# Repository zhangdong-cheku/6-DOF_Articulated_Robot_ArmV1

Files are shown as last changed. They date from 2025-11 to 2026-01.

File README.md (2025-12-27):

# 6-DOF_Articulated_Robot_ArmV1
六自由度关节式机械臂6-DOF Articulated Robot ArmV1

机械臂本体五个自由度，末端执行器是一个自由度，如果有兴趣，可以在机械臂的基础上增加一个末端执行器。

<p align="center">
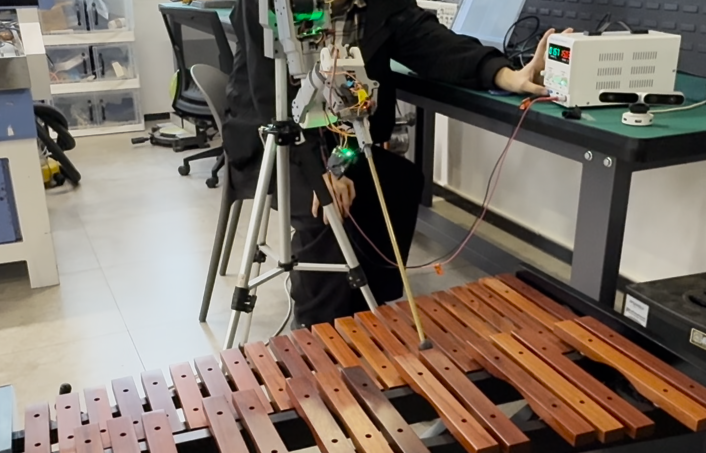
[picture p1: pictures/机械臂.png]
  
  
本项目是一款低成本、高扩展性的六自由度关节式机械臂，专为机器人爱好者、科研人员和学生设计。支持精准运动控制、路径规划、自定义任务编程，可广泛应用于教学演示、自动化实验、小型生产线作业等场景。
核心目标：降低机械臂开发门槛，提供从硬件设计到软件控制的完整开源方案，助力开发者快速搭建属于自己的机械臂系统。

This project is a low-cost, highly scalable six-degree-of-freedom articulated robotic arm, specially designed for robot enthusiasts, researchers and students. It supports precise motion control, path planning, and custom task programming, and can be widely applied in scenarios such as teaching demonstrations, automated experiments, and small-scale production line operations. 
Core objective: Lower the threshold for robotic arm development, provide a complete open-source solution from hardware design to software control, and assist developers in quickly building their own robotic arm systems.
<p align="center">
  

## 致谢
感谢项目组成员岳国文，田宇鑫在项目迭代与数据处理中做出的贡献，感谢张冬老师在项目方案上的精准指导，也感谢项目组其他成员的通力协作。

## 加入社区

<p align="center">
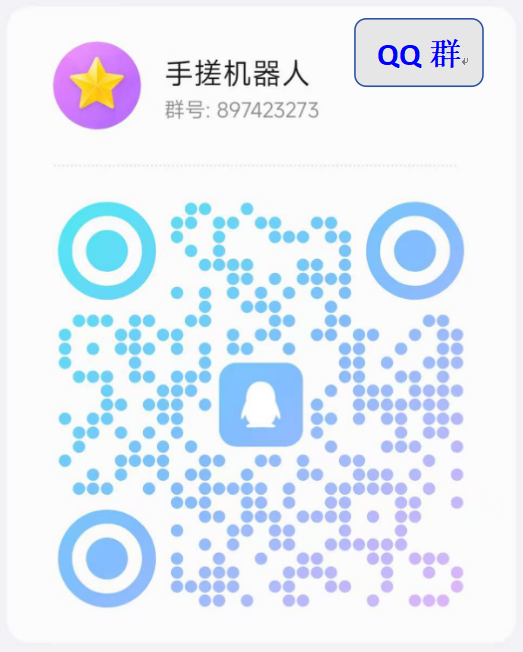
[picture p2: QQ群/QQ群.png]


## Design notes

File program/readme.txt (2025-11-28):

烧录前准备
在arduino_project中
1.修改int Motor_PP = 7;，将极对数修改为自己使用电机的极对数。
2.setPowerSupplyVoltage(15.6);  //!< 设置供电电压：15.6V，可设置为自己电源的供电电压，建议不超过15.6V

在Ble_Handler.cpp和Ble_Handler.h中
1.可通过修改uint8_t my_device_id = 6;  #define MY_DEVICE_ID 6  ,设置自己设备的ID号

在FOC.h中
1.#define GEAR_RATIO 225.0f，用来设置关节的减速比

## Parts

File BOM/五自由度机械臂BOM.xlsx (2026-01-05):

名称 | 规格 | 数量 | 价格（单价） | 淘宝链接 | 备注
控制板 | 2-F0C单板（含电流传感器） | 5 | 77 | https://item.taobao.com/item.htm?from=cart&id=888754845091&skuId=5734451161826&upStreamPrice=7700 | 控制板可以多买一个，防止板子烧坏，AS5600磁编码可以多准备几个。
无刷电机 | 5010-360KV标配 | 5 | 70 | https://item.taobao.com/item.htm?from=cart&id=707986229345&skuId=5146420343156&upStreamPrice=7000
磁编码器AS5600 |  | 5 | 6.05 | https://item.taobao.com/item.htm?id=944751197481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
耗材 | 银色10102【无料盘】 | 3 | 58.65 | https://detail.tmall.com/item.htm?from=cart&id=693972799714&skuId=4921295904036&upStreamPrice=5865 | 耗材的颜色决定你机械臂的颜色
红黑线纯铜二芯电线 | 无氧纯铜 红黑线2芯（10米）0.75平方毫米 | 1 | 12.65 | https://item.taobao.com/item.htm?ali_trackid=318_fea39e69447c78ab8311cdb6c2fe511b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
虎头润滑脂 | 0# | 1 | 60 | https://detail.tmall.com/item.htm?id=555743121657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 | 组装完成后，要涂润滑脂，降低摩擦。（也可以选择其它品牌粘稠度低的润滑脂）
电子端子线 | SH1.0/5P/10CM单头(5条) | 1 | 3.3 | https://item.taobao.com/item.htm?id=565360096163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 | 备用件，可以多准备一些
MR106ZZ普通级尺寸6*10*3 |  | 120 | 54 | https://item.taobao.com/item.htm?id=771766393836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
轴承6701ZZ |  | 20 | 23.8 | https://item.taobao.com/item.htm?from=cart&id=990391948357&skuId=6121385790174&upStreamPrice=119
轴承6809ZZ |  | 5 | 20 | https://detail.tmall.com/item.htm?from=cart&id=612627762952&skuId=4622777205969&upStreamPrice=400
圆柱头螺钉M3*50 |  | 20-30个 | 9.22（两包） | https://detail.tmall.com/item.htm?from=cart&id=684328822068&skuId=5937566553025&upStreamPrice=251
圆柱头螺钉M3*16 |  | 30 | 4.71（一包） | https://detail.tmall.com/item.htm?from=cart&id=684328822068&skuId=5937566337918&upStreamPrice=261
圆柱头螺钉M3*25 |  | 30 | 6.28（一包） | https://detail.tmall.com/item.htm?from=cart&id=684328822068&skuId=5937566337934&upStreamPrice=398
圆柱头螺钉M3*3 |  | 10 | 4.45（一包） | https://detail.tmall.com/item.htm?from=cart&id=684328822068&skuId=5937566337977&upStreamPrice=235
沉头螺钉M3*4 |  | 20 | 6（一包） | https://detail.tmall.com/item.htm?from=cart&id=693377485791&skuId=5968664858309&upStreamPrice=398
B型平键6*6*15 |  | 5 | 14 | https://detail.tmall.com/item.htm?from=cart&id=986192425745&skuId=5949249685444&upStreamPrice=180
六角铜柱4*14 |  | 5 | 29 | https://detail.tmall.com/item.htm?from=cart&id=542213588710&skuId=5026844310974&upStreamPrice=480
热熔螺母M3*4*5 |  | 120 | 18.48（7包） | https://detail.tmall.com/item.htm?from=cart&id=809364062256&skuId=5496541308886&upStreamPrice=144
螺母M3 |  | 20-30个 | 5.03（一包） | https://detail.tmall.com/item.htm?id=634913276373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
赛克电烙铁 | 852D+(标配) |  | 230 | https://item.taobao.com/item.htm?id=927081057466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 | 实验室型号，仅供参考
鼎策学生电源 | DC3020S30V20A锁定/预设编码调节 |  | 430 | https://item.taobao.com/item.htm?id=563785564816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
备注：如果发现错误，欢迎大家在技术交流群里提出，会及时更新。

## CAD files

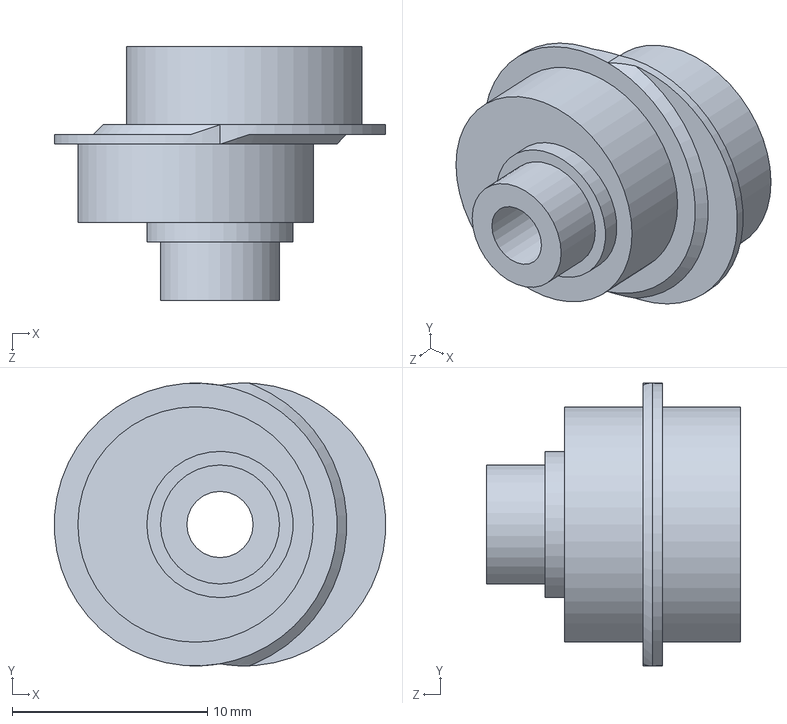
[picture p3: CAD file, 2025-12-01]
1.第一自由度/1.5.偏心轴。.SLDPRT
17.0 x 14.5 x 13.0 mm

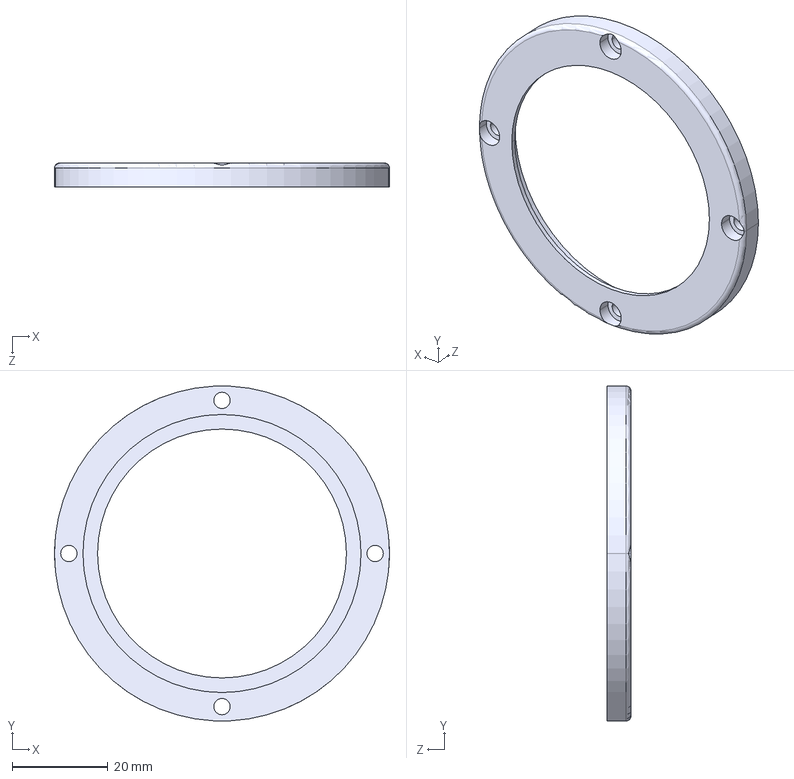
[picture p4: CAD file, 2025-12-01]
2.第二自由度/2.2二级外圈.STEP
70.0 x 70.0 x 5.00 mm

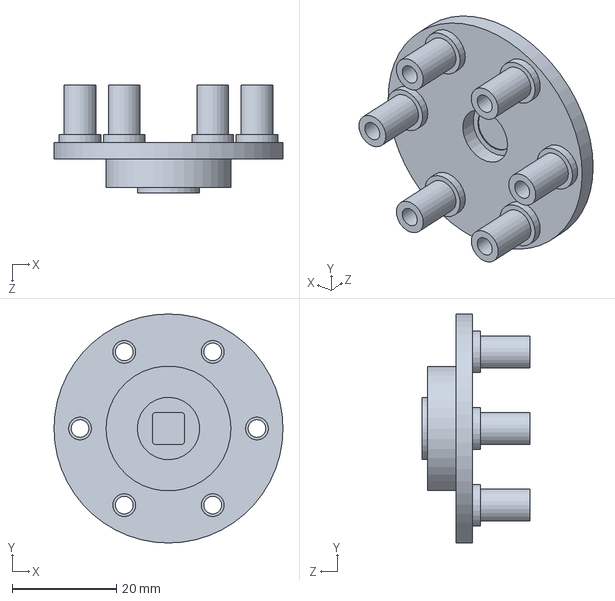
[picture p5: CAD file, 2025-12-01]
3.第三自由度/3.7.一级输出轴接二级..SLDPRT
44.0 x 44.0 x 20.7 mm

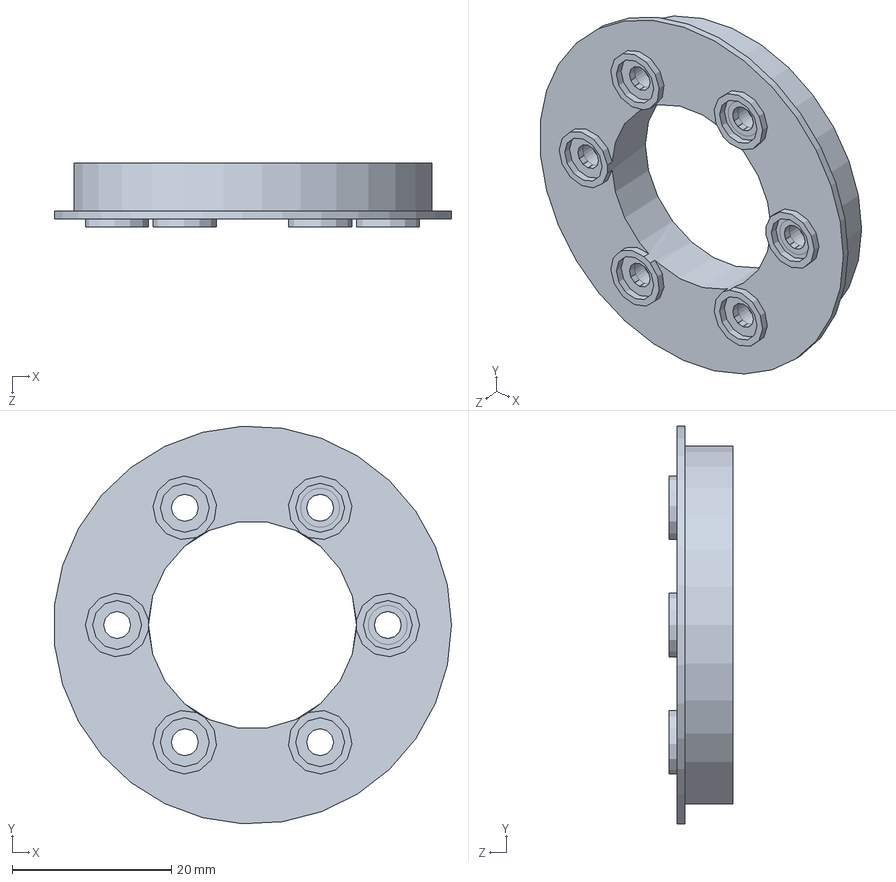
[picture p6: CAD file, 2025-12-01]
5.第五自由度/5.9.一级输出轴内.SLDPRT
49.9 x 49.9 x 8.00 mm

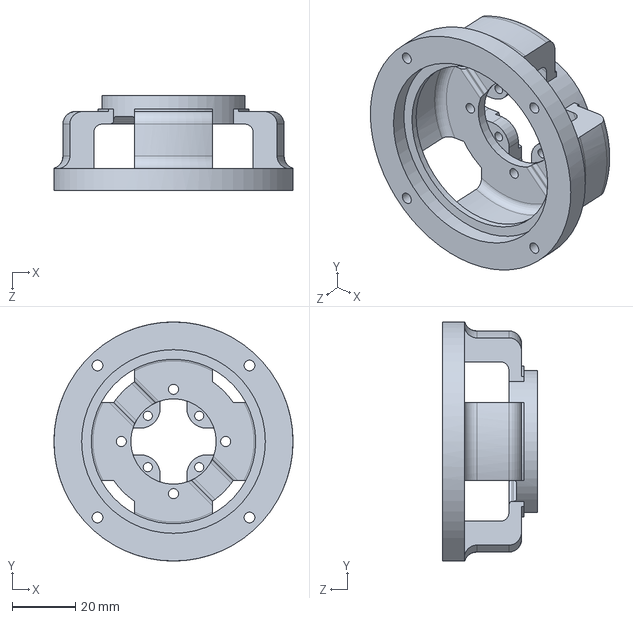
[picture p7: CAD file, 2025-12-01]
补充/5010电机支架.SLDPRT
75.6 x 75.6 x 30.0 mm

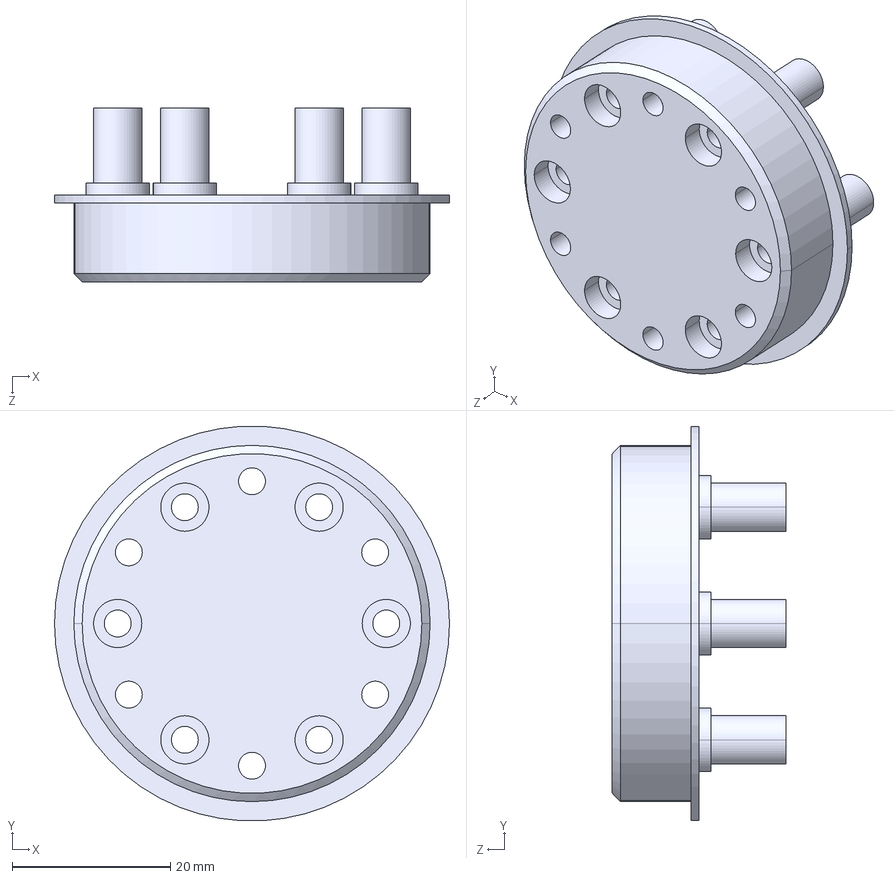
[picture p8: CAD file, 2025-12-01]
补充/通用零件/3.二级输出轴外.STEP
50.0 x 49.9 x 22.0 mm

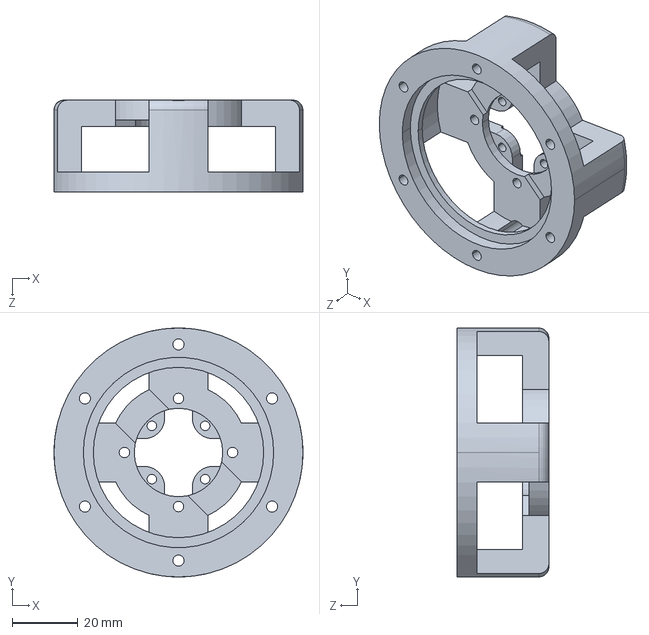
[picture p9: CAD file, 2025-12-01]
1.第一自由度/1.5010电机支架，方编码器.SLDPRT
76.0 x 76.0 x 28.0 mm

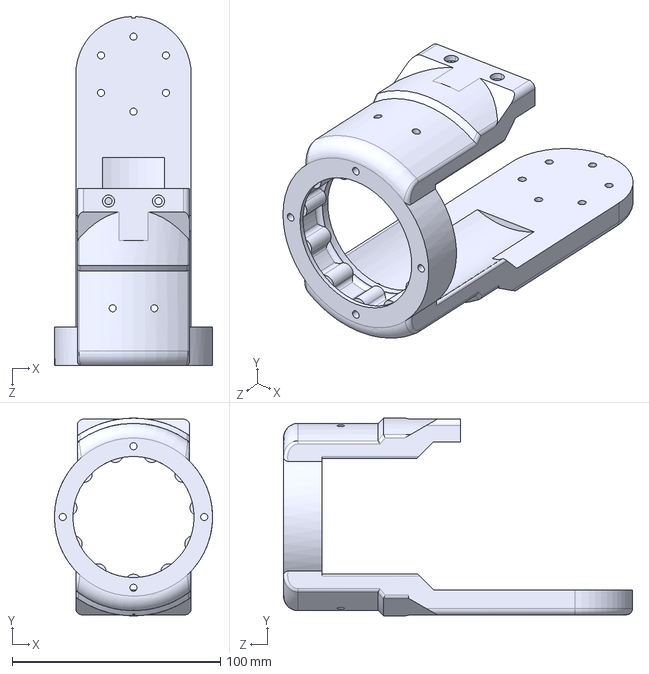
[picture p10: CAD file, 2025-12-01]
3.第三自由度/3.二级针齿壳.STEP
76.0 x 95.0 x 167.7 mm

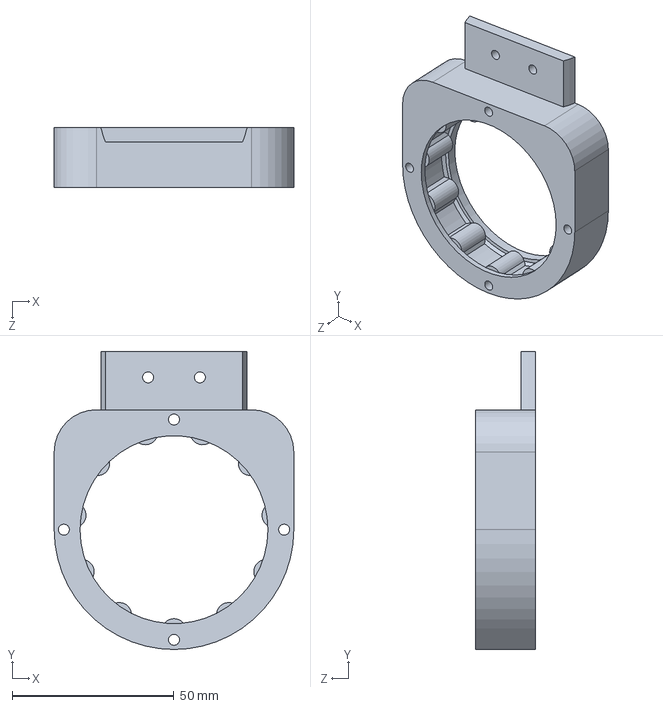
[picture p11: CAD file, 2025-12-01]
5.第五自由度/二级针齿壳.SLDPRT
74.0 x 92.0 x 18.5 mm

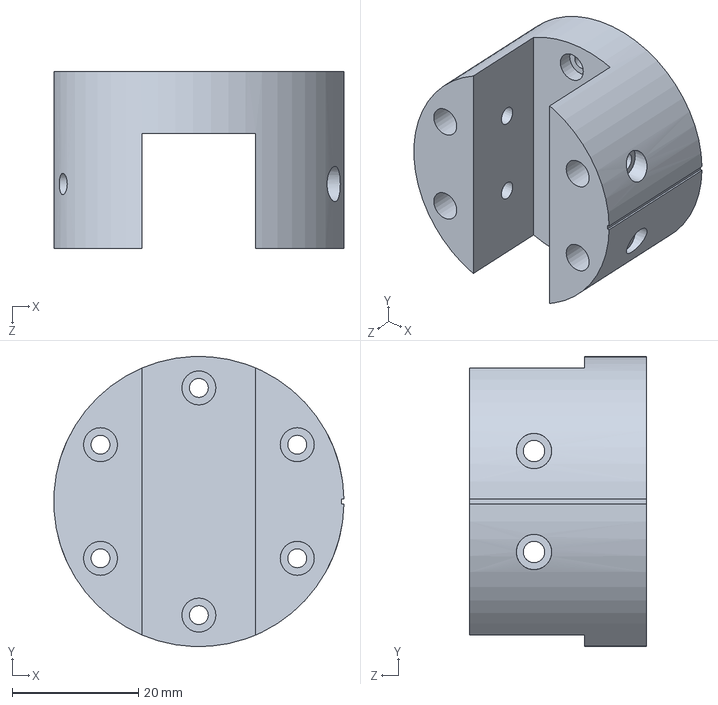
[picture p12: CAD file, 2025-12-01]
补充/肘关节链接件.SLDPRT
46.0 x 46.0 x 28.0 mm

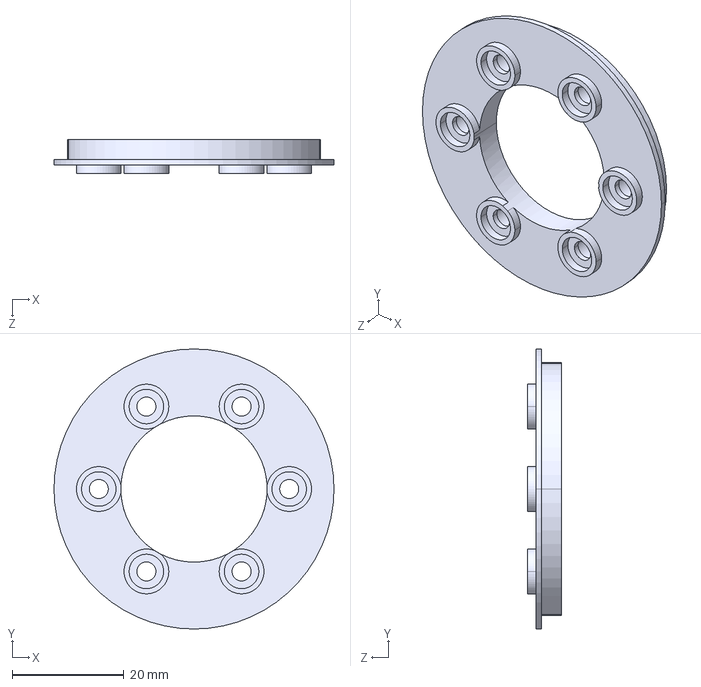
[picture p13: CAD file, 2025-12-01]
补充/通用零件/15.二级输出轴内.STEP
50.0 x 50.0 x 6.00 mm

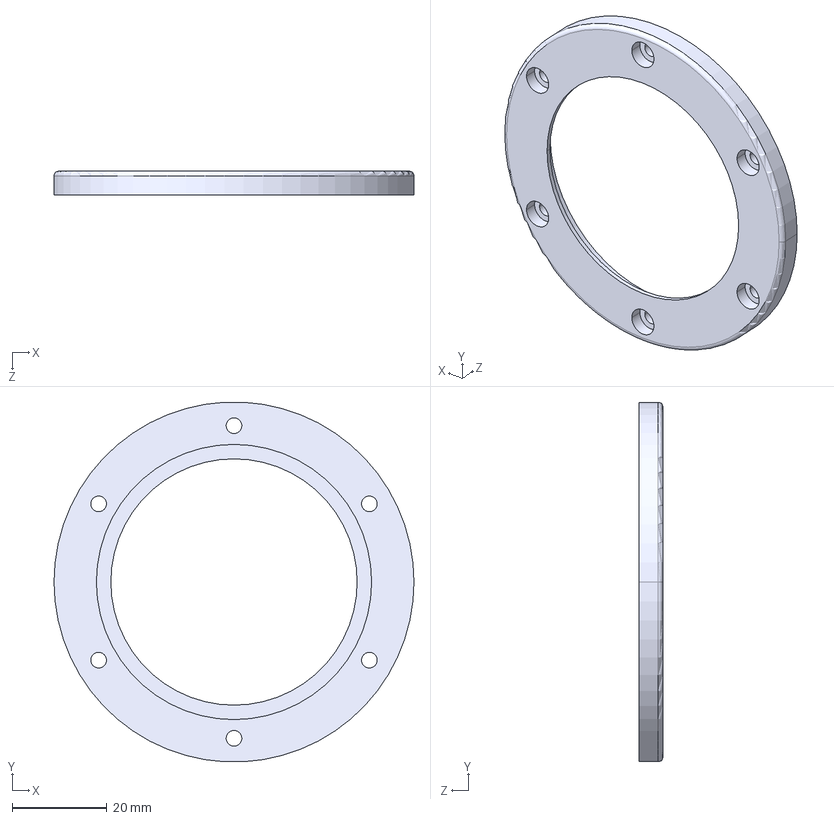
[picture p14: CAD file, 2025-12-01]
1.第一自由度/1.1.二级外圈.STEP
76.0 x 75.9 x 5.00 mm

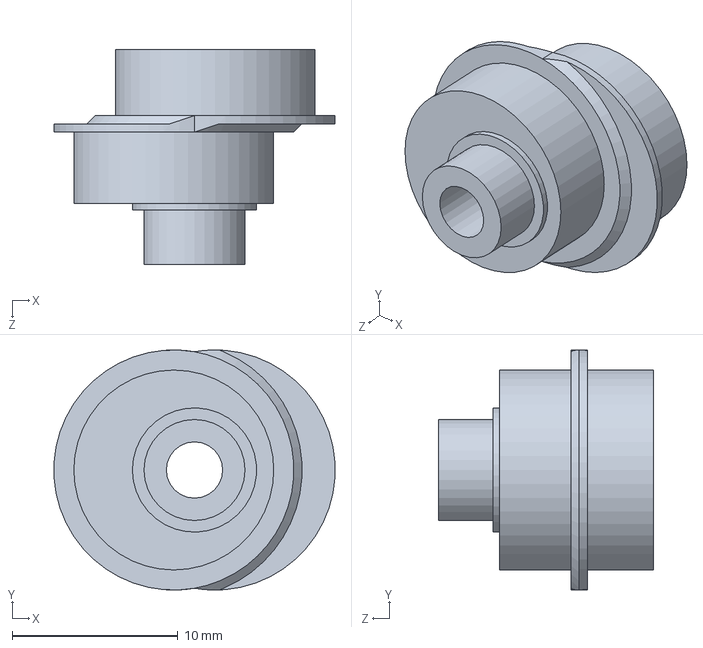
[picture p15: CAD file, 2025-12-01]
2.第二自由度/2.5.偏心轴。需要两个.SLDPRT
17.0 x 14.5 x 13.0 mm

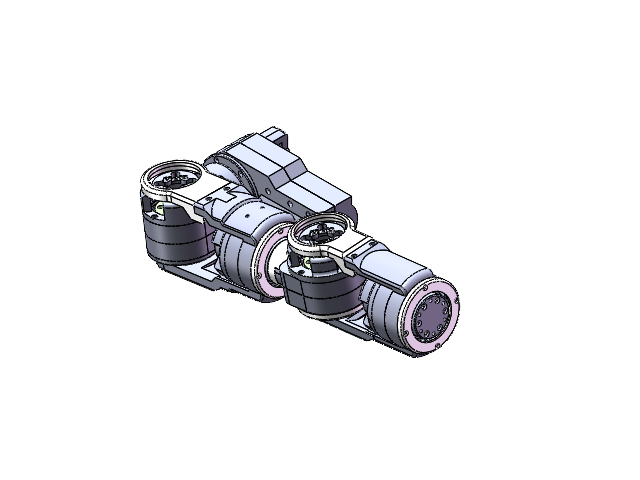
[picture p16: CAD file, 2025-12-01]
装配体/机械臂五自由度装配体.SLDASM
1.2.二级壳中针轮圆
1.1一级针轮壳圆
1.1.二级外圈
2..2二级壳中针轮
2.2二级外圈
2.2一级针齿壳
2.25010电机支架
5010电机支架 x 2
二级外圈 x 2
肘关节链接件
一级针齿壳
4.4一级针齿壳
3.二级输出轴外 x 5
7.一级输出轴接二级. x 4
15.二级输出轴内 x 5
9.一级输出轴内 x 5
1.5010电机轴 x 3
2.1输出结构1新
2.7.一级输出轴接二级.
3.二级针齿壳
3.10-yi级针齿壳 x 2
1.5010电机支架，方编码器
3.辅助结构
5.10二级针齿壳
4.二级外圈
5.辅助结构
5.5010电机轴
4.5010电机支架

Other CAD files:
4.第四自由度/4.5.偏心轴。.SLDPRT
2.第二自由度/2.9.一级输出轴内.SLDPRT
4.第四自由度/4.7.一级输出轴接二级..SLDPRT
3.第三自由度/3.15.二级输出轴内.SLDPRT
1.第一自由度/1.1.二级外圈.SLDPRT
1.第一自由度/1.1一级针轮壳.SLDPRT
1.第一自由度/1.2.二级壳中针轮.SLDPRT
1.第一自由度/1.3.二级输出轴外.SLDPRT
1.第一自由度/1.4.轴承隔圈，需要两组12个.SLDPRT
1.第一自由度/1.5.二级输出轴内.SLDPRT
1.第一自由度/1.5.偏心轴。需要两个.SLDPRT
1.第一自由度/1.5010电机轴.SLDPRT
1.第一自由度/1.6.摆线轮，需要4片.SLDPRT
1.第一自由度/1.6.摆线轮，需要4片.STEP
1.第一自由度/1.7.一级输出轴接二级..SLDPRT
1.第一自由度/1.9.一级输出轴内.SLDPRT
1.第一自由度/yiji摆线轮，需要4片.STEP
2.第二自由度/2..2二级壳中针轮.SLDPRT
2.第二自由度/2..2二级壳中针轮.STEP
2.第二自由度/2.15.二级输出轴内.SLDPRT
2.第二自由度/2.1输出结构1新.SLDPRT
2.第二自由度/2.1输出结构1新.STEP
2.第二自由度/2.25010电机支架.SLDPRT
2.第二自由度/2.2一级针齿壳.SLDPRT
2.第二自由度/2.2一级针齿壳.STEP
2.第二自由度/2.2二级外圈.SLDPRT
2.第二自由度/2.3.二级输出轴外.SLDPRT
2.第二自由度/2.4.轴承隔圈，需要两组12个.SLDPRT
2.第二自由度/2.5.偏心轴。.SLDPRT
2.第二自由度/2.5010电机轴.SLDPRT
2.第二自由度/2.6.摆线轮，需要4片.SLDPRT
2.第二自由度/2.6.摆线轮，需要4片.STEP
2.第二自由度/2.7.一级输出轴接二级..SLDPRT
3.第三自由度/3.10-yi级针齿壳.SLDPRT
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

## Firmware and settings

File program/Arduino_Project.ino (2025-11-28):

// ============================================================================
// 文件：Pos_Current_Velocity.ino
// 功能：FOC系统主程序 - 位置-速度-电流三环控制
// 说明：实现基于AS5600传感器的位置闭环、速度闭环和电流闭环控制
// ============================================================================

// ============================================================================
// 头文件包含
// ============================================================================
#include "FOC.h"           //!< FOC核心库头文件 - 包含FOC算法实现
#include "Ble_Handler.h"   //!< BLE通信处理头文件 - 支持无线控制功能

// ============================================================================
// 系统配置参数
// ============================================================================

// 传感器和电机参数配置
int Sensor_DIR = -1;  //!< 传感器方向：-1表示反向，1表示正向
                      //!< 用于校正传感器读数与电机实际旋转方向的关系

int Motor_PP = 7;     //!< 电机极对数：7对极（14极电机）
                      //!< 定义电机的磁极数量，用于电角度计算

// 备用配置（注释状态）
//int Motor_PP = 14;     //!< 电机极对数：14对极（28极电机）- 备用配置

// ============================================================================
// PID控制器限幅参数
// ============================================================================

// 位置环PID限幅参数
int angle_PID_limit = 60;  //!< 角度PID输出限幅：70度/秒
                          //!< 限制位置环控制器的最大输出速度

// 速度环PID限幅参数  
float vel_PID_limit = 6.5;  //!< 速度PID输出限幅：6.5安培（电流）
                           //!< 限制速度环控制器的最大输出电流

// 备用配置（注释状态）
//int angle_PID_limit = 5;  //!< 角度PID输出限幅：5度/秒 - 备用配置

// ============================================================================
// 函数：setup
// 功能：系统初始化函数
// 说明：在系统启动时执行一次，完成硬件和软件的初始化
// ============================================================================
void setup() {
  // 串口通信初始化
  Serial.begin(115200);  //!< 初始化串口通信，波特率115200

  // 电机使能控制
  pinMode(12, OUTPUT);
  digitalWrite(12, HIGH);

  // FOC系统参数配置
  setPowerSupplyVoltage(15.0);

  calibrateSensor(Motor_PP, Sensor_DIR);

  // BLE通信初始化
  initBLEServer();

  // 启动帮助提示
  Serial.println("=== 串口控制帮助 ===");
  Serial.println("输入格式：");
  Serial.println("  RUN | MODE RUN | MODE=RUN — 切换运行模式");
  Serial.println("  STANDBY | MODE STANDBY | MODE=STANDBY — 切换待机模式");
  Serial.println("  OUT_DEG=<度数> — 设置输出轴角度（度）");
  Serial.println("  <弧度值> — 设置电机轴目标角（弧度）");
  Serial.println("  HELP 或 ? — 显示本帮助");
  Serial.println("提示：GEAR_RATIO 设置在 FOC.h 中。");
}

// ============================================================================
// 全局变量定义
// ============================================================================
int count = 0;  //!< 循环计数器 - 可用于调试或定时任务

// ============================================================================
// 函数：loop
// 功能：主循环函数
// 说明：系统主循环，持续执行控制算法和通信处理
// ============================================================================
void loop() {
  // 通信处理
  BLE_Server_Loop();

  // 模式分支：运行模式执行完整控制；待机仅刷新传感器
  if (control_mode == MODE_RUN) {
    runFOC();
    configureAnglePID(1, 0, 0, 10000, angle_PID_limit);
    configureVelocityPID(0.02, 1, 0, 10000, vel_PID_limit);
    configureCurrentPID(5, 200, 0, 10000);
    setMotorVelocityWithAngle(getSerialMotorTarget());
  } else {
    S0.Sensor_update();
  }

  // 串口命令处理
  readSerialCommand();

  // 每1秒输出一次 motor_target（调试），并显示输出轴角度
  static unsigned long last_log_ms = 0;
  unsigned long now_ms = millis();
  if (now_ms - last_log_ms >= 1000) {
    float target_out_deg = motor_target * 180.0f / PI / GEAR_RATIO;
    float actual_rad = getMotorAngle();
    float actual_out_deg = actual_rad * 180.0f / PI / GEAR_RATIO;
    Serial.printf("[DEBUG] mode=%s, target=%.4f rad, out_deg=%.2f°, actual=%.4f rad, actual_out_deg=%.2f°\n",
                  (control_mode == MODE_RUN ? "RUN" : "STANDBY"),
                  motor_target, target_out_deg,
                  actual_rad, actual_out_deg);
    last_log_ms = now_ms;
  }
}

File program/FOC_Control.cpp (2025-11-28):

#include "FOC.h"

// ============================================================================
// 函数：setMotorTorque
// 功能：力矩控制函数（电流环控制）
// 参数：Target - 目标电流值（力矩指令）
// 说明：这是最内层的电流环控制，直接控制电机的输出力矩
// ============================================================================
void setMotorTorque(float Target) {
    // 计算电流环PID输出：目标电流 - 实际测量电流
    float current_error = Target - getMotorCurrent();
    float pid_output = current_loop_M0(current_error);
    
    // 使用PID输出和电角度设置电机力矩
    setTorque(pid_output, electricalAngle());
}

// ============================================================================
// 函数：setMotorVelocityWithAngle
// 功能：位置-速度-电流三环控制（外环到内环的级联控制）
// 参数：Target - 目标位置（弧度）
// 说明：实现完整的三环控制策略：
//       位置环（外环）→ 速度环（中环）→ 电流环（内环）
// ============================================================================
void setMotorVelocityWithAngle(float Target) {
    // 1. 位置环控制：计算位置误差并转换为角度PID
    //    将弧度转换为角度（180/PI），计算位置误差
    float position_error = (Target - getMotorAngle()) * 180 / PI;
    float angle_pid_output = calculateAnglePID(position_error);
    
    // 2. 速度环控制：将位置环输出作为速度环的参考值
    //    速度环输入 = 位置环输出 - 实际速度
    float velocity_error = angle_pid_output - getMotorVelocity();
    float iq_ref = calculateVelocityPID(velocity_error);
    
    // 3. 电流限幅：限制q轴电流参考值在安全范围内
    iq_ref = _constrain(iq_ref, -I_MAX_CMD, I_MAX_CMD);
    
    // 4. 调用力矩控制函数（电流环）
    setMotorTorque(iq_ref);
}

// ============================================================================
// 函数：runFOC
// 功能：FOC主控制循环
// 说明：每个控制周期需要执行的核心任务
//       1. 更新传感器数据（角度）
//       2. 更新电流传感器数据
// ============================================================================
void runFOC() {
    // 更新磁编码器角度数据
    S0.Sensor_update();
    
    // 更新三相电流测量值
    CS_M0.getPhaseCurrents();
}

// ============================================================================
// 函数：readSerialCommand
// 功能：串口通信命令处理
// 返回值：接收到的完整命令字符串
// 说明：处理来自串口的控制命令，支持多字符命令的接收和解析
// ============================================================================
String readSerialCommand() {
    static String received_chars;  // 静态缓冲区，保存未完成的命令字符
    String command = "";           // 完整的命令字符串

    while (Serial.available()) {
        char inChar = (char)Serial.read();
        // 行结束（支持\n或\r）
        if (inChar == '\n' || inChar == '\r') {
            command = received_chars;   // 取一整行
            received_chars = "";       // 清空缓冲

            // 规范化命令：去空白、转大写
            String cmd = command;
            cmd.trim();
            if (cmd.length() == 0) return command; // 空行直接返回
            String upper = cmd;
            upper.toUpperCase();

            // 帮助提示：HELP / ? / H
            if (upper == "HELP" || upper == "?" || upper == "H") {
                Serial.println("=== 串口控制帮助 ===");
                Serial.println("输入格式：");
                Serial.println("  RUN | MODE RUN | MODE=RUN — 切换运行模式");
                Serial.println("  STANDBY | MODE STANDBY | MODE=STANDBY — 切换待机模式");
                Serial.println("  OUT_DEG=<度数> — 设置输出轴角度（度）");
                Serial.println("  <弧度值> — 设置电机轴目标角（弧度）");
                Serial.println("  HELP 或 ? — 显示本帮助");
                Serial.println("提示：GEAR_RATIO 设置在 FOC.h 中。");
                // 同步当前目标信息
                float out_deg_dbg = motor_target * 180.0f / PI / GEAR_RATIO;
                Serial.printf("[SERIAL] 当前目标: %.4f rad, out_deg=%.2f°\n", motor_target, out_deg_dbg);
                return command;
            }

            // 模式切换：RUN / STANDBY
            if (upper == "RUN" || upper == "MODE RUN" || upper == "MODE=RUN") {
                enterRun();
                Serial.println("[SERIAL] Mode -> RUN");
                float out_deg_dbg = motor_target * 180.0f / PI / GEAR_RATIO;
                Serial.printf("[SERIAL] target=%.4f rad, out_deg=%.2f°\n", motor_target, out_deg_dbg);
                return command;
            }
            if (upper == "STANDBY" || upper == "MODE STANDBY" || upper == "MODE=STANDBY") {
                enterStandby();
                Serial.println("[SERIAL] Mode -> STANDBY");
                float out_deg_dbg = motor_target * 180.0f / PI / GEAR_RATIO;
                Serial.printf("[SERIAL] target=%.4f rad, out_deg=%.2f°\n", motor_target, out_deg_dbg);
                return command;
            }

            // 目标角设置（输出角度，单位度）：OUT_DEG=xxx
            if (upper.startsWith("OUT_DEG=")) {
                int eq = upper.indexOf('=');
                float out_deg = cmd.substring(eq + 1).toFloat();
                motor_target = out_deg * GEAR_RATIO * (PI / 180.0f);
                Serial.printf("[SERIAL] out_deg %.2f° -> motor_target %.4f rad\n", out_deg, motor_target);
                // 再回显转换结果，保持一致的格式
                Serial.printf("[SERIAL] target=%.4f rad, out_deg=%.2f°\n", motor_target, out_deg);
                return command;
            }

            // 直接数字：按弧度设置 motor_target
            char c0 = upper.charAt(0);
            if (c0 == '-' || (c0 >= '0' && c0 <= '9')) {
                motor_target = cmd.toFloat();
                float out_deg_dbg = motor_target * 180.0f / PI / GEAR_RATIO;
                Serial.printf("[SERIAL] motor_target set to %.4f rad\n", motor_target);
                Serial.printf("[SERIAL] target=%.4f rad, out_deg=%.2f°\n", motor_target, out_deg_dbg);
                return command;
            }

            // 未识别命令，打印提示
            Serial.print("[SERIAL] Unknown command: ");
            Serial.println(cmd);
            Serial.println("输入 'HELP' 或 '?' 获取命令格式帮助");
        } else {
            // 累加字符
            received_chars += inChar;
        }
    }
    return command;  // 返回本轮解析到的完整命令（可能为空）
}

// ============================================================================
// 函数：getSerialMotorTarget
// 功能：BLE蓝牙目标值处理
// 返回值：处理后的电机目标位置（弧度）
// 说明：处理来自蓝牙的电机控制命令，支持角度到弧度的转换和去重处理
// ============================================================================
float getSerialMotorTarget() {
    static float last_target = 0.0f;  // 保存上一次的目标值，用于去重
    
    // 检查是否有新的BLE命令到达
    if (new_command) {
        new_command = false;  // 重置命令标志
        
        // BLE传输的是输出角度（度），需要转换为电机轴角度
        float out_deg = ble_motor_target;
        
        // 角度转换：输出角度 → 电机机械角度（弧度）
        // 考虑减速比和角度单位转换
        float motor_rad = out_deg * GEAR_RATIO * (PI / 180.0f);

        // 去重处理：只有当目标值变化超过阈值时才更新
        if (fabs(motor_rad - last_target) > 0.0001f) {
            last_target = motor_rad;     // 更新上一次目标值
            motor_target = motor_rad;    // 设置新的电机目标
            
            // 调试信息：显示转换过程和参数
            Serial.printf("[DEBUG] BLE输出角度 %.2f° -> 电机目标 %.4f rad (ratio=%g)\n",
                          out_deg, motor_rad, GEAR_RATIO);
        } else {
            // 目标值未变化时的调试信息
            Serial.printf("[DEBUG] BLE目标未改变: 输出角度 %.2f°\n", out_deg);
        }
    }
    
    // 返回当前电机目标位置
    return motor_target;
}

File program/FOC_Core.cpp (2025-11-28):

#include "FOC.h"
#include "Ble_Handler.h"

// ============================================================================
// 函数：normalizeAngle
// 功能：角度归一化处理
// 参数：angle - 输入角度（弧度）
// 返回值：归一化到[0, 2π)范围内的角度
// 说明：将任意角度值转换为0到2π之间的等效角度，便于三角函数计算
// ============================================================================
float normalizeAngle(float angle) {
    // 使用模运算将角度限制在2π周期内
    float a = fmod(angle, 2*PI);
    // 处理负角度情况，转换为正角度
    return a >= 0 ? a : (a + 2*PI);
}

// ============================================================================
// 函数：setPwm
// 功能：三相PWM输出控制
// 参数：Ua, Ub, Uc - 三相电压值
// 说明：将三相电压转换为PWM占空比并输出到电机驱动器
// ============================================================================
void setPwm(float Ua, float Ub, float Uc) {
    // 电压限幅：确保电压值在电源电压范围内
    Ua = _constrain(Ua, 0.0f, voltage_power_supply);
    Ub = _constrain(Ub, 0.0f, voltage_power_supply);
    Uc = _constrain(Uc, 0.0f, voltage_power_supply);
    
    // 电压转占空比：计算每相的PWM占空比（0-1范围）
    float dc_a = _constrain(Ua / voltage_power_supply, 0.0f, 1.0f);
    float dc_b = _constrain(Ub / voltage_power_supply, 0.0f, 1.0f);
    float dc_c = _constrain(Uc / voltage_power_supply, 0.0f, 1.0f);
    
    // PWM输出：将占空比转换为8位PWM值（0-255）并输出
    ledcWrite(0, dc_a*255);  // A相PWM输出
    ledcWrite(1, dc_b*255);  // B相PWM输出
    ledcWrite(2, dc_c*255);  // C相PWM输出
}

// ============================================================================
// 函数：setTorque
// 功能：FOC核心算法 - 力矩控制
// 参数：Uq - q轴电压（力矩分量），angle_el - 电角度（弧度）
// 说明：实现FOC算法的核心部分，包括帕克逆变换和克拉克逆变换
// ============================================================================
//void setTorque(float Uq, float angle_el) {
//    // q轴电压限幅：限制在±电源电压/2范围内
//    Uq = _constrain(Uq, -(voltage_power_supply)/2, (voltage_power_supply)/2);
//    float Ud = 0;  // d轴电压设为0（磁场定向控制，d轴不产生力矩）
//    
//    // 电角度归一化处理
//    angle_el = normalizeAngle(angle_el);
//    
//    // 帕克逆变换（Park逆变换）：将dq坐标系转换为αβ坐标系
//    // Uα = -Uq * sin(θ) + Ud * cos(θ)
//    // Uβ = Uq * cos(θ) + Ud * sin(θ)
//    // 由于Ud=0，简化为：
//    Ualpha = -Uq*sin(angle_el);  // α轴电压分量
//    Ubeta = Uq*cos(angle_el);    // β轴电压分量
//    
//    // 克拉克逆变换（Clarke逆变换）：将αβ坐标系转换为三相ABC坐标系
//    // 标准三相逆变器电压公式：
//    Ua = Ualpha + voltage_power_supply/2;                    // A相电压
//    Ub = (sqrt(3)*Ubeta-Ualpha)/2 + voltage_power_supply/2;  // B相电压
//    Uc = (-Ualpha-sqrt(3)*Ubeta)/2 + voltage_power_supply/2; // C相电压
//    
//    // 调用PWM输出函数，将电压转换为实际PWM信号
//    setPwm(Ua, Ub, Uc);
//}

void setTorque(float Uq, float angle_el)
{
  if (Uq < 0)
    angle_el += _PI;
  Uq = abs(Uq);

  angle_el = normalizeAngle(angle_el + _PI_2);
  int sector = floor(angle_el / _PI_3) + 1;
  // calculate the duty cycles
  float T1 = _SQRT3 * sin(sector * _PI_3 - angle_el) * Uq / voltage_power_supply;
  float T2 = _SQRT3 * sin(angle_el - (sector - 1.0) * _PI_3) * Uq / voltage_power_supply;
  float T0 = 1 - T1 - T2;

  float Ta, Tb, Tc;
  switch (sector)
  {
  case 1:
    Ta = T1 + T2 + T0 / 2;
    Tb = T2 + T0 / 2;
    Tc = T0 / 2;
    break;
  case 2:
    Ta = T1 + T0 / 2;
    Tb = T1 + T2 + T0 / 2;
    Tc = T0 / 2;
    break;
  case 3:
    Ta = T0 / 2;
    Tb = T1 + T2 + T0 / 2;
    Tc = T2 + T0 / 2;
    break;
  case 4:
    Ta = T0 / 2;
    Tb = T1 + T0 / 2;
    Tc = T1 + T2 + T0 / 2;
    break;
  case 5:
    Ta = T2 + T0 / 2;
    Tb = T0 / 2;
    Tc = T1 + T2 + T0 / 2;
    break;
  case 6:
    Ta = T1 + T2 + T0 / 2;
    Tb = T0 / 2;
    Tc = T1 + T0 / 2;
    break;
  default:
    Ta = 0;
    Tb = 0;
    Tc = 0;
  }

  float Ua = Ta * voltage_power_supply;
  float Ub = Tb * voltage_power_supply;
  float Uc = Tc * voltage_power_supply;

  setPwm(Ua, Ub, Uc);
}

// ============================================================================
// 函数：electricalAngle
// 功能：计算电角度
// 返回值：归一化后的电角度（弧度）
// 说明：将机械角度转换为电角度，考虑极对数和旋转方向
// ============================================================================
float electricalAngle() {
    // 电角度 = 极对数 × 机械角度 × 方向 - 零电角度偏移
    // 公式：θ_elec = PP × θ_mech × DIR - θ_zero
    return normalizeAngle((float)(DIR * PP) * S0.getMechanicalAngle() - zero_electric_angle);
}

// ============================================================================
// 函数：setPowerSupplyVoltage
// 功能：系统硬件初始化
// 参数：power_supply - 电源电压值
// 说明：初始化PWM、编码器、电流传感器等硬件外设
// ============================================================================
void setPowerSupplyVoltage(float power_supply) {
    // 设置电源电压全局变量
    voltage_power_supply = power_supply;
    
    // PWM引脚初始化
    pinMode(pwmA, OUTPUT);  // A相PWM引脚
    pinMode(pwmB, OUTPUT);  // B相PWM引脚
    pinMode(pwmC, OUTPUT);  // C相PWM引脚
    
    // PWM通道配置：30kHz频率，8位分辨率
    ledcSetup(0, 30000, 8);  // 通道0：A相
    ledcSetup(1, 30000, 8);  // 通道1：B相
    ledcSetup(2, 30000, 8);  // 通道2：C相
    
    // PWM引脚与通道绑定
    ledcAttachPin(pwmA, 0);  // A相引脚绑定到通道0
    ledcAttachPin(pwmB, 1);  // B相引脚绑定到通道1
    ledcAttachPin(pwmC, 2);  // C相引脚绑定到通道2
    
    Serial.println("完成PWM初始化设置");

    // AS5600磁编码器初始化
    // I2C总线配置：SDA=19, SCL=18, 400kHz速率
    S0_I2C.begin(19, 18, 400000UL);
    S0.Sensor_init(&S0_I2C);  // 编码器传感器初始化
    Serial.println("编码器加载完毕");

    // 速度环PID控制器重新初始化
    vel_loop_M0 = PIDController{.P = 2, .I = 0, .D = 0, .ramp = 100000, .limit = voltage_power_supply/2};
    
    // 电流传感器初始化
    CS_M0.init();
}

// ============================================================================
// 函数：calibrateSensor
// 功能：传感器校准程序
// 参数：_PP - 电机极对数，_DIR - 旋转方向
// 说明：执行电机零电角度校准，确定磁场定向的基准位置
// ============================================================================
void calibrateSensor(int _PP, int _DIR) {
    // 设置电机参数
    PP = _PP;   // 极对数
    DIR = _DIR; // 旋转方向
    
    // 第一步：施加固定力矩使电机转到特定位置（3π/2位置）
    // 这个位置有助于确定零电角度
    setTorque(3, _3PI_2);
    delay(1000);  // 等待1秒让电机稳定
    
    // 第二步：更新编码器读数
    S0.Sensor_update();
    
    // 第三步：计算并保存零电角度
    // 零电角度是电机当前位置的电角度，作为后续计算的基准
    zero_electric_angle = electricalAngle();
    
    // 第四步：释放力矩，电机回到自由状态
    setTorque(0, _3PI_2);
    
    // 输出校准结果
    Serial.print("0电角度：");
    Serial.println(zero_electric_angle);
}

// 新增：进入待机模式（零扭矩、目标继承当前角）
void enterStandby() {
  control_mode = MODE_STANDBY;
  // 继承当前电机轴角，作为后续恢复运行时的初始目标
  motor_target = getMotorAngle();
  // 立即置零力矩，确保进入待机后无驱动电流
  setTorque(0, electricalAngle());
  Serial.println("[MODE] Enter STANDBY: zero torque, target=curr angle");
}

// 新增：进入运行模式（继承当前角为初始目标，避免跳变）
void enterRun() {
  control_mode = MODE_RUN;
  // 以当前电机轴角作为运行初始目标，避免从待机恢复出现位置跳变
  motor_target = getMotorAngle();
  Serial.println("[MODE] Enter RUN: inherit current angle as target");
  // 进入 RUN 时发送一次实际输出侧角度（度），用于反馈到客户端
  float angle_deg = getCurrentAngleDegrees();
  sendMultiStructAngleFeedback(angle_deg);
  char resp[64];
  snprintf(resp, sizeof(resp), "%d:FEEDBACK:%.2f", getMyDeviceID(), angle_deg);
  sendBLEResponse(resp);
}
